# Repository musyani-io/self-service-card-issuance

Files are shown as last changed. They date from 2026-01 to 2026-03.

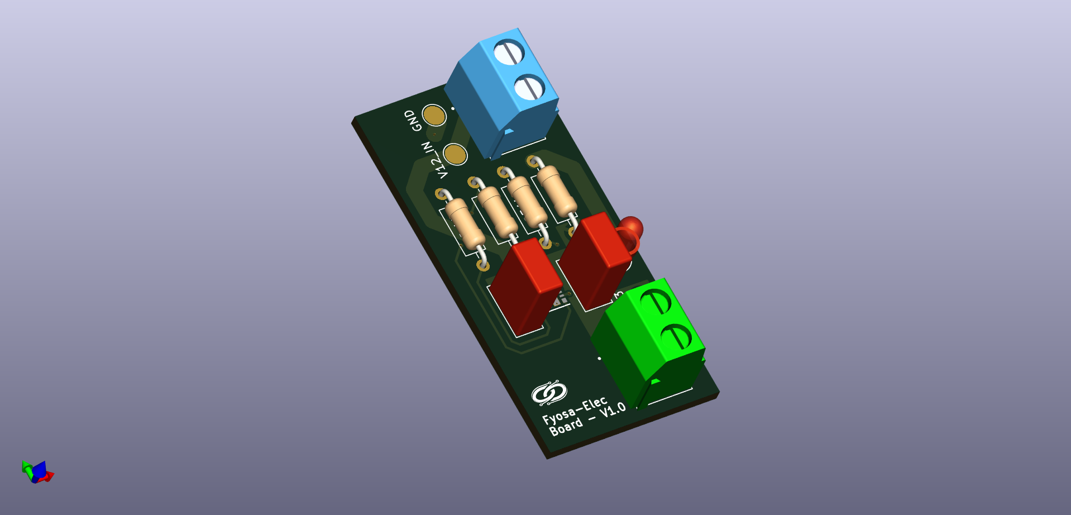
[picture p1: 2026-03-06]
hardware/3d/buck_3V3.png

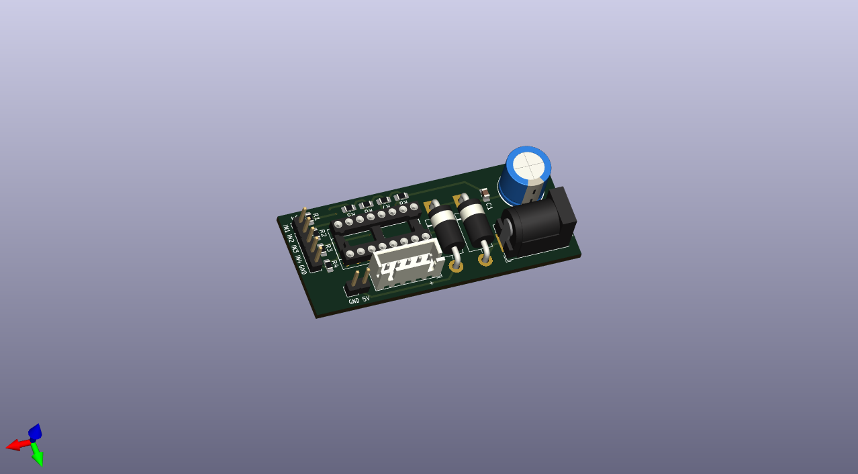
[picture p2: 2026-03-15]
hardware/3d/motor_driver.png

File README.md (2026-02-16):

# Self-Service Card Issuance System

Automated, secure, 24/7 student ID card distribution kiosk with a dual-controller architecture and full auditability.

## Overview

This system dispenses pre-printed student ID cards after identity verification. It is designed for unattended operation with deterministic control, mechanical safety, and a complete audit trail.

## System Architecture

Two controllers split responsibilities:

- **Raspberry Pi 5 (High-Level Control)**
  - User interface and session management
  - OTP-based authentication and policy enforcement
  - Computer vision pipeline for OCR/verification
  - Database access and audit logging

- **STM32 (Low-Level Control)**
  - Motor/actuator control and transport timing
  - Sensor acquisition (optical, limit switches, etc.)
  - Jam detection and recovery state machine
  - Hardware safety interlocks

Communication occurs over a 3.3V SPI link with a message protocol and acknowledgements to ensure safe, deterministic execution.

## Key Features

- **OTP Authentication**: SMS-based verification with configurable timeouts and retries
- **Computer Vision**: OCR-driven ID extraction with preprocessing and failure handling
- **Audit Trail**: Immutable transaction logs with timestamps and device context
- **Safety Enforcement**: Jam detection, limit checks, and fault isolation
- **Offline Tolerance**: Local caching for continued operation during network issues
- **Mock Hardware**: Back-end testing without physical hardware

## Repository Structure

- [DESCRIPTION.md](DESCRIPTION.md): Short project description and scope
- [backend/](backend/): Raspberry Pi application (auth, dispense flow, logging, DB access, communications)
- [computer_vision/](computer_vision/): CV pipeline for detection, OCR, and verification
- [hardware/](hardware/): Schematics, PCB layouts, BOMs, and EasyEDA project files
- [docs/](docs/): Research, system guidelines, and internal documentation
- [usage/](usage/): Minimal usage examples and entry points

## Data Flow (High Level)

1. User initiates session on the kiosk UI.
2. OTP is issued and verified.
3. The CV pipeline validates the card identity.
4. The Pi sends a dispense command to STM32.
5. STM32 executes the transport state machine and reports status.
6. Results and telemetry are logged.

## Hardware Integration

Hardware artifacts are organized under [hardware/](hardware/) and include:

- Schematics and PCB layouts
- BOMs and component datasheets
- EasyEDA project files

## Development Notes

- The Pi side is responsible for policies, logging, and vision.
- The STM32 side is responsible for deterministic actuation and safety.
- All dispense actions must be logged with outcome codes.

## License

See [LICENSE](LICENSE).

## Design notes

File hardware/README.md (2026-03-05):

# Hardware Design and Integration

This directory contains the electrical design, PCB layout, and mechanical specifications for the self-service card issuance kiosk controller board, designed using KiCAD.

## Design Overview

The hardware implements a dual-controller architecture:

- **Raspberry Pi 5**: High-level application control, UI, vision processing, and system logging
- **STM32 Microcontroller**: Real-time actuator control, sensor acquisition, and safety interlocks
- **SPI Communication**: 3.3V differential signaling for deterministic inter-controller messaging

## Design Files

KiCAD project files are located in [kicad/](kicad/) with four independent circuit modules:

- **buck_3V3.kicad_pro**: 12V → 3.3V buck regulator for logic and STM32 supply
- **buck_5V1.kicad_pro**: 12V → 5V synchronous buck regulator (10 A) for Raspberry Pi and peripherals
- **motor_driver.kicad_pro**: High-side MOSFET drivers and PWM control for DC motor actuation
- **reverse_polarity.kicad_pro**: Input reverse-polarity protection circuit using P-channel MOSFET

Each project includes schematic (.kicad_sch), PCB layout (.kicad_pcb), and project configuration files.

## Schematic Exports

Generated schematics are exported as PDFs in the [schematics/](schematics/) directory for documentation and reference.

## PCB Layout

PCB layout files and manufacturing exports are available in [pcb/](pcb/):

- Multi-layer stackup optimized for power distribution and thermal management
- Dedicated copper area under buck regulator SW nodes for heat spreading
- Ground plane separation (PGND/AGND) with single-point Kelvin connection

## Simulations

Circuit simulations and verification are performed in [simulations/](simulations/) using Proteus (.pdsprj files) for behavioral validation of power stages and driver circuits.

## 3D Models and Renders

3D visualizations are provided in [3d/](3d/):

- Component placement and thermal analysis renderings
- PCB assembly reference

## Bill of Materials

Component lists and sourcing information:

- [bom/motor_driver.csv](bom/motor_driver.csv): Motor driver stage components

## Component Datasheets

Reference datasheets for key active components are provided in [datasheets/](datasheets/):

- Buck regulator specifications and timing parameters
- Motor driver absolute maximum ratings and thermal considerations
- Reverse-polarity MOSFET characteristics

## Design Constraints and Specifications

- **Input voltage**: 12 V nominal (fused at 10 A)
- **Output rails**: 5 V @ 8 A (Pi/display), 3.3 V @ 3 A (logic/STM32)
- **Operating mode**: 12V → 5V buck in 1 MHz forced CCM for Raspberry Pi loads
- **Safety**: Dual fusing, reverse-polarity protection, limit switch monitoring on STM32

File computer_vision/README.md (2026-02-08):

# Computer Vision Module

## Overview

Image preprocessing and OCR detection module for the Automated Self-Service Student ID Card Issuance System. Handles image capture, preprocessing pipeline (grayscale conversion, resizing, ROI extraction), and OCR-based ID extraction for card identification and verification.

---

## Quick Start

### Installation

```bash
pip install -r requirements.txt
```

Ensure `opencv-python`, `pytesseract`, and `pillow` are installed in your environment.

---

## Module Structure

```bash
computer_vision/
├── core/              # Core CV functions (image_utils, ocr tools)
├── pipeline/          # Processing pipeline orchestration
├── config/            # Configuration files (camera, processing params)
├── tests/             # Manual and automated tests
├── data/              # Sample images, debug outputs, calibration data
├── docs/              # API reference, setup guides
└── utils/             # Logging, file I/O helpers
```

---

## Implementation Status

**Overall Progress: 14%** (6 phases)

**Phase 1: Environment Setup** 🚧 68%

- ✅ Software installation complete
- ✅ Development environment configured
- ⏳ Camera hardware acquisition pending
- ✅ Test data partially prepared

**Phase 2: Image Capture** ⏳ 0%

- ⏳ Camera configuration
- ⏳ Camera interface implementation
- ⏳ Testing suite

**Phase 3: Image Preprocessing** 🚧 16%

- ✅ Basic preprocessing functions (grayscale, resize, ROI crop)
- ⏳ Advanced preprocessing (blur, thresholding, morphology)
- ⏳ Processing pipeline
- ⏳ Testing suite

**Phase 4: OCR Detection** ⏳ 0%

- ⏳ OCR detection
- ⏳ OCR parsing/validation
- ⏳ Edge case handling
- ⏳ Testing suite

**Phase 5: Error Handling** ⏳ 0%

- ⏳ Custom exceptions
- ⏳ Exception integration
- ⏳ Retry logic

**Phase 6: Integration & Testing** ⏳ 0%

- ⏳ Public API
- ⏳ Database integration
- ⏳ End-to-end testing
- ⏳ Performance benchmarking

---

## Data Organization

### Input Images

Place sample ID card images in:

```bash
data/test_cards/
```

### Debug Outputs

Processed images saved to:

```bash
data/debug_outputs/
```

Includes intermediate preprocessing results for visual inspection.

---

## Dependencies

See [requirements.txt](requirements.txt) for full list.

---

## Notes & Limitations

- **No camera integration yet**: Works with static images only
- **Fixed orientation**: Assumes cards are consistently oriented
- **ROI hardcoded**: Bottom-half crop; configurable in future iterations
- **Testing environment**: Local development with mock data; not production-ready

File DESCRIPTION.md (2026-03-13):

# Automated Self-Service Student ID Card Issuance System

## Overview

This project implements a prototype **Automated Self-Service Student ID Card Issuance System** designed to securely distribute **pre-printed student ID cards** in a university environment. The system eliminates long queues, limited working hours, and manual sorting by enabling **on-demand, 24/7 card retrieval** through a secure, auditable, and electromechanically controlled kiosk.

The system focuses strictly on **card distribution**, not card printing or identity creation.

---

## Problem Statement

In many universities, including the University of Dar es Salaam, student ID cards are issued through a largely manual process:

- Cards are pre-printed and later distributed at college offices
- Students wait days to weeks before collection
- Distribution is constrained to working hours
- Staff must manually sort and handle large volumes of cards
- The process is prone to inefficiency, congestion, and human error

The bottleneck is **secure distribution**, not printing.

---

## Project Objective

### Main Objective

To design and implement an **automated, secure, and reliable self-service system** for issuing pre-printed student ID cards with full transaction logging and minimal human intervention.

### Specific Objectives

- Implement a deterministic actuator control system capable of selecting and dispensing a single card
- Implement secure student authentication using SMS-based One-Time Passwords (OTP)
- Implement computer vision for card identification and verification
- Maintain a complete audit trail of all transactions
- Enforce security policies for invalid attempts and physical tampering
- Evaluate system performance using measurable operational metrics

---

## System Scope and Limitations

### Included

- Secure dispensing of **pre-printed** ID cards
- Mechanical card transport, stopping, and storage
- OTP-based authentication
- Computer vision verification
- Local (mock) database for testing
- Audit logging and fault reporting

### Excluded

- On-device PVC card printing
- Payment or billing systems
- Mobile applications
- Direct access to live university databases (unless authorized)

---

## System Architecture

The system uses a **dual-controller architecture** to separate high-level decision logic from real-time mechanical control.

### High-Level Controller (Raspberry Pi 5)

Responsibilities:

- User interface (display, keypad, scanner input)
- SMS OTP generation and verification
- Database access and transaction logging
- Computer vision processing
- Security policy enforcement
- Issuing structured commands to the real-time controller

This controller handles **logic, authentication, and traceability**.

### Low-Level Controller (STM32)

Responsibilities:

- Real-time motor and actuator control
- Sensor acquisition (optical sensors, limit switches, jam detection)
- Deterministic execution of card transport and dispensing
- Mechanical safety enforcement
- Status and fault reporting to the high-level controller

This controller handles **physical determinism and safety**.

### Communication

- Protocol: SPI
- Logic level: 3.3 V
- Direction: Command–status exchange between Raspberry Pi and STM32

---

## Card Handling and Transport Concept

- Cards are **pre-printed** and manually loaded by authorized staff
- Each card contains a **printed student ID** used as a unique identifier (OCR)
- Cards are stored in indexed compartments
- A roller-based transport mechanism:
  - Accepts cards from the input slot
  - Moves cards to a camera inspection point
  - Stops cards at a repeatable reference position
  - Routes cards to storage or rejects them back to the user

All motion is **mechanically constrained** to ensure alignment and repeatability.

---

## Functional Workflow

### 1. Preload and Mapping Phase (Staff Operation)

- Staff loads pre-printed cards into the machine
- Each card is scanned using a camera
- Card student ID (OCR) is mapped to a storage index and student record
- Mapping is stored in the database

### 2. Notification Phase

- Once cards are available, the system sends an SMS notification
- Each message includes an OTP valid for a single retrieval attempt

### 3. Retrieval Phase (Student Operation)

1. Student inserts or scans their expired ID card
2. Student details are displayed on the screen
3. Student enters the OTP received via SMS
4. System verifies identity and OTP
5. High-level controller authorizes dispensing
6. Low-level controller retrieves and ejects the correct card
7. Transaction is logged for auditing

### 4. Rejection and Error Handling

- If verification or vision checks fail:
  - Card can be safely rejected back to the user
- If mechanical or security faults occur:
  - System halts and notifies the administrator

---

## Security Model

### Logical Security

- SMS-based OTP authentication
- Limited retry attempts
- Temporary lockout after repeated failures
- Database-backed audit logging

### Physical Security

- Tamper detection sensors
- Jam and stall detection
- Motor torque limiting
- Manual administrator reset for recovery

The system prioritizes **human safety over mechanical force**.

---

## Performance Evaluation Metrics

The prototype is evaluated using:

- Authentication success rate
- Average card retrieval time
- Dispense accuracy (correct card delivered)
- Fault detection and recovery effectiveness
- System uptime and reliability

---

## Key Engineering Contributions

- Application of vending-machine principles to sensitive identity distribution
- Correct separation of real-time and non-real-time system responsibilities
- Secure, auditable automation for institutional ID management
- Mechanically enforced precision to reduce software complexity

---

## Intended Use

This prototype is intended for:

- Academic evaluation
- Demonstration of embedded systems integration
- Exploration of secure automated kiosks in institutional environments

It is **not** intended for direct deployment without further industrial hardening.

---

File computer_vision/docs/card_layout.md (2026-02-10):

# Student ID Card Layout Documentation

**Purpose:** Document the physical and logical layout of your university's student ID cards to guide OCR implementation.

**Card Type/Version:** University of Dar es Salaam - from 2022 Editions  
**Measured By:** Samuel Dan Musyani

---

## 1. Physical Card Specifications

### Card Dimensions

- **Width:** 88 mm
- **Height:** 55 mm
- **Standard:** CR80 (Almost this standard)
- **Thickness:** 1 mm

### Card Material

- Material: PVC
- Surface finish: Glossy
- Color: Whitish background

### Printing Quality

- Print quality: Fair
- Text clarity: Low contrast
- Any visible wear on sample cards? Yes

---

## 2. Student ID Field Specification

This is the **PRIMARY** field your OCR system must extract.

### Location on Card

From **top-left corner** of the card:

- **Distance from left edge:** 1.5 mm
- **Distance from top edge:** 29 mm
- **Width of ID field:** 23 mm
- **Height of ID field:** 3.5 mm

### ID Format

- **Exact format pattern:** 2020-04-12345
- **Regex pattern:** `r'\d{4}-\d{2}-\d{5}'`
- **Total characters:** 13 (including separators)
- **Numeric only?** Yes (with hyphens)
- **Special characters:** Hyphens

### Sample Valid IDs

```bash
- 2022-04-07227
- 2022-04-11472
- 2022-04-09050
```

### ID Field Properties

- **Font name:** Calibri
- **Font size:** 9 pt
- **Font style:** Bold
- **Text color:** Blue
- **Background color/pattern:** Whitish
- **Text orientation:** Horizontal
- **Fixed-width font?** Yes

---

## 3. Additional Text Fields (Secondary)

### Field 1: Student Name

- **Location:** 1.5 mm from left, 21 mm from top, 57mm width, 4 mm height
- **Format:** Structured (`last_name, first_name middle_name`)
- **Font:** Calibri, Size: 9 pt, Color: Blue, Type: Bold
- **Purpose in system:** Display

### Field 2: Program/Major

- **Location:** 1.5 mm from left, 37 mm from top, 57 mm width, 4 mm height
- **Format:** B.Sc. in `Course name` (Electronics Engineering, Telecommunication Engineering)
- **Font:** Calibri, Size: 9 pt, Color: Red, Type: Blue
- **Purpose in system:** Display

### Field 3: Card Expiry Date

- **Location:** 18 mm from left, 40 mm from top, 21 mm width, 4 mm height
- **Format:** "DD/MM/YYYY"
- **Font:** Calibri, Size: 9 pt, Color: Red, Type: Bold
- **Purpose in system:** Validation

---

## 4. ROI (Region of Interest) Coordinates

These will be used to extract specific text regions during OCR.

**Calculation method:** Coordinates as **percentage** of card width/height (0.0 to 1.0).

### Anchor-Based ROI (Final Offsets)

Anchor label: **NAME** (top-left of the anchor text box). Offsets are fractions of card width/height from the anchor top-left.

```python
ANCHOR_ROI_OFFSETS = {
    'name': {
        'dx': -0.008,
        'dy': 0.064,
        'w': 0.648,
        'h': 0.073,
    },
    'student_id': {
        'dx': -0.010,
        'dy': 0.203,
        'w': 0.261,
        'h': 0.086,
    },
    'program': {
        'dx': -0.013,
        'dy': 0.322,
        'w': 0.648,
        'h': 0.072,
    },
    'expiry_date': {
        'dx': 0.166,
        'dy': 0.394,
        'w': 0.238,
        'h': 0.073,
    },
}
```

---

## 5. Challenges and Special Considerations

### Text Recognition Challenges

- [x] Low contrast text
- [x] Reflective/glossy surface causes glare
- [x] Background pattern/watermark interferes with OCR
- [ ] Font is unusual or ornamental
- [ ] Text is very small
- [x] Colored text (not black)

### Positioning Challenges

- [ ] ID field location varies between card batches
- [ ] Card might be slightly rotated when inserted
- [x] Multiple text regions close together

### Environmental Challenges

- [ ] Card might have stickers/tape on it
- [x] Card edges are worn
- [ ] Card is laminated/sealed

---

## 7. Reference Images

### High-Quality Reference Card

- Save a clean, well-lit photo: `data/test_cards/reference.jpg`
- Annotate with anchor label if possible: `data/test_results/reference_annotated.jpg`
- Include measurements marked on image

### Multiple Sample Cards

Create a directory with diverse examples:

```bash
data/test_cards/
  ├── reference_card_front.jpg          (high quality, well-lit)
  ├── sample_card_01.jpg                 (typical condition)
  ├── sample_card_02.jpg
  ├── sample_card_challenging_01.jpg    (poor lighting)
  └── sample_card_challenging_02.jpg    (damaged/worn)
```

---

## 8. Configuration Template

Once you've documented above, use this template for `config/ocr_config.py`:

```python
# Card Layout Configuration
# Based on physical measurements from card_layout.md
# University of Dar es Salaam - 2022 Edition Cards

CARD_PHYSICAL = {
    'width_mm': 88,
    'height_mm': 55,
    'standard': 'CR80',  # Close to CR80 standard (85.60×53.98mm)
}

# Standard output size for perspective-corrected cards
# Maintains aspect ratio: 88/55 = 1.6
CARD_OUTPUT_SIZE = (880, 550)  # Width × Height in pixels (10px per mm)

ANCHOR_OCR = {
    'anchor_texts': ['NAME'],  # Update to the exact printed label on your card
    'min_confidence': 50,
    'psm': 6,
    'oem': 3,
    'char_whitelist': 'ABCDEFGHIJKLMNOPQRSTUVWXYZ: ',
}

# Offsets relative to anchor top-left (fractions of card width/height)
ANCHOR_ROI_OFFSETS = {
    'name': {
        'dx': 0.000,
        'dy': 0.000,
        'w': 0.648,
        'h': 0.073,
    },
    'student_id': {
        'dx': 0.000,
        'dy': 0.145,
        'w': 0.261,
        'h': 0.064,
    },
    'program': {
        'dx': 0.000,
        'dy': 0.291,
        'w': 0.648,
        'h': 0.072,
    },
    'expiry_date': {
        'dx': 0.188,
        'dy': 0.345,
        'w': 0.238,
        'h': 0.073,
    },
}

# Student ID Validation
STUDENT_ID_PATTERN = r'\d{4}-\d{2}-\d{5}'  # Format: 2022-04-07227
VALID_YEAR_RANGE = (2015, 2030)
ID_TOTAL_LENGTH = 13  # Including hyphens

# OCR Settings
TESSERACT_CONFIG = {
    'psm': 6,  # Assume uniform block of text
    'oem': 3,  # Default OCR Engine Mode
    'char_whitelist': '0123456789-',  # Only digits and hyphens for ID
}

# Font Properties (for reference)
FONT_PROPERTIES = {
    'name': 'Calibri',
    'size_pt': 9,
    'style': 'Bold',
    'color': 'Blue',  # Text color (may need color-specific preprocessing)
}

# Known Challenges
CHALLENGES = [
    'Low contrast text (blue on white)',
    'Glossy surface causing glare',
    'Background watermark interference',
    'Colored text (not black)',
    'Card edge wear',
    'Multiple text regions close together',
]
```

---

## 9. Measurement Checklist

Before proceeding to Phase 2, verify you have:

- [x] Physical card dimensions documented
- [x] Student ID format with regex pattern defined
- [x] Student ID location measured (from top-left corner)
- [x] Student ID font properties recorded
- [x] ROI percentages calculated
- [x] At least one reference card image saved
- [ ] At least 5 sample cards photographed at various angles
- [x] All challenges/variations listed
- [ ] Card layout diagram or annotated image created

---

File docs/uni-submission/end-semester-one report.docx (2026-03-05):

UNIVERSITY OF DAR ES SALAAM

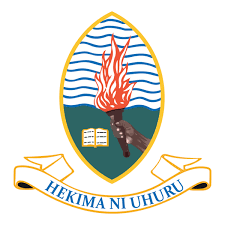
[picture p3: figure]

COLLEGE OF INFORMATION AND COMMUNICATION TECHNOLOGY

DEPARTMENT OF ELECTRONICS AND TELECOMMUNICATIONS ENGINEERING

FINAL YEAR REPORT-MID SEMESTER ONE

PROJECT TITLE: DESIGN AND IMPLEMENTATION OF AN AUTOMATIC ID CARD ISSUANCE SYSTEM

Student’s Name: Samuel Dan Musyani

Registration Number: 2022-04-09050

Supervisor’s Name: Dr. Hashimu Iddi

Supervisor’s Signature:

# ABSTRACT

The issuance of student identification cards in many higher learning institutions is often characterized by long processing times as a result of manual verification within a narrow working window. This project proposes the design and implementation of an automated self-service student ID card issuance system aimed at improving efficiency, security and all-time reliability of issuance process. The system is an embedded system with peripheral devices for user authentication, data collection, card issuance, back-end communication together with database access. The proposed project will be evaluated based on authentication success rate, dispense rate, issuance accuracy, and system’s reliability.

The outcome of this project is expected to be a functional prototype demonstrating an automated secure student ID card issuance system suitable for University environments.

# TABLE OF CONTENTS

# LIST OF TABLES

# LIST OF FIGURES

# LIST OF ABBREVIATIONS

ABBREVIATIONS | LONG FORM
2FA | 2-Factor Authentication
API | Application Program Interface
CAD | Computer Aided Design
CLK | Clock
CS | Chip Select
DB | Database
GB | Gigabyte
ID | Identification
IoT | Internet of Things
MISO | Master In Slave Out
MOSI | Master Out Slave In
OCR | Optical Character Recognition
OS | Operating System
OTP | One Time Password
PVC | Poly-Vinyl Chloride
PWM | Pulse-Width Modulation
RAM | Random Access Memory
SMS | Short Message Service
SPI | Serial Peripheral Interface
Wi-Fi | Wireless Fidelity

# CHAPTER ONE: INTRODUCTION

## 1.1 BACKGROUND

Universities commonly issue student ID cards that serve as proof of registration and campus identification for various services to students. At the University of Dar es Salaam, the card collection process, which occurs immediately after students have completed registration, involves queuing at the responsible office for collection. However, for a high volume of students, this results in long waiting times, narrow service windows (only operating during working hours), and staff exhaustion.

Therefore, the project aims to develop a prototype of an Automated ID Card Issuance System that sorts and gives out pre-printed ID cards to students on demand at all times. The system integrates a microcontroller that controls actuators in real-time, a single-board computer that performs computer vision (for ID identification), student’s identity authentication, logging of various activities, and back-end integration. The intended solution aims to reduce distribution time while ensuring secure ID card distribution as it is.

## 1.2 PROBLEM STATEMENT

The current student ID card issuance process at University of Dar es Salaam involves a waiting period of approximately one week after registration due to delayed card availability in the individual’s college. After release, the card collection also requires students to queue and sort a bunch of ID cards. So, for a high volume of students, the staff responsible suffers significant work strain. On top of that, fixed hours also hinder the sorting capacity of students' issuance per time. As a result, card issuance for registered students takes up to several days, which may bring inconvenience to students.

## 1.3 MAIN OBJECTIVE

Design and implementation of an Automated ID Card Issuance System for pre-printed student ID cards with secure authentication and audit logging while serving students at all times.

## 1.4 SPECIFIC OBJECTIVE

1. To implement a reliable control system for actuators using a microcontroller capable of selecting and dispensing a single card from a pile of cards in a stored compartment.
2. To implement a computer board application that gives out authentication OTPs, verifies the student’s set pin, receives the user registration data, verifies it against a database, and communicates the command to the microcontroller.
3. To implement robust logging of each transaction details in database for auditing and debugging.
4. To implement security policy that uses SMS-delivered OTPs as authentication mechanism, and also enforce measures to deal with invalid attempts and communication to system admin.
5. To evaluate system performance using metrics such as average card retrieval time, authentication success, error handling and dispense rate.
6. To produce a formal report involving design of the prototype at various milestones.

## 1.5 SIGNIFICANCE OF STUDY

- Operational efficiency: the proposed system reduces long queues and waiting times by allowing students to retrieve ID cards on demand without any staff intervention.
- Reduced administrative burden: the system performs automation which replaces the repetitive tasks done by a university staff allowing them to focus on higher level tasks.
- Scalability, accessibility and replicability: Although the proposed system is implemented as a prototype for UDSM, the system can be adopted by other institutions such as banks for card applications. Also, access to students retrieving their ID cards beyond standard normal working hours.
- Academic contribution: the project demonstrates practical application of embedded systems, back-end software and other mechanical design theory and automation studied as theory in various academic year(s).

## 1.6 SCOPE AND LIMITATIONS

This project focuses on the design and implementation of an Automated ID Card Issuance System which integrates the software part (back-end, user interaction and computer vision verification) and hardware part with microcontroller and actuators for card sorting and dispensing the said card. Therefore, the prototype does not implement on-device printing of the PVC cards, mobile application or payment gateway.

The system intends to use a mock database for testing unless institutional access is granted.

# CHAPTER TWO: LITERATURE REVIEW

In this chapter, various existing systems, projects and technologies related to the proposed project are reviewed. The purpose of the review is to understand different approaches, scope, limitations and gaps and hence, establish basis of the proposed project. Therefore, the following points gathered below feature ideas with similar concepts as the proposed project.

## 2.1 RELATED PROJECTS

- Automatic and Smart Vending systems: these are some self-service systems that provide mostly goods (foods) to users without much human intervention, mostly observed in supermarkets for snacks and beverages. These systems have two categories: non-IoT machines, which operate by giving physical cash to the machine, and IoT machines, which work with cashless payments and track the availability of stock, locations to satisfy customer preferences by using microcontrollers (Ratnasri & Sharmilan, 2021). Also, some vending systems apply image processing with deep learning to detect and categorize various target objects of interest in the image. These kinds of vending machines also implement a weight data acquisition part to increase the accuracy of target object detection (Xia, K., Fan, H., Huang, J., Wang, H., Ren, J., Jian, Q., & Wei, D).
- System architectures and control strategies: in most of the dispensing applications, generally a microcontroller is used with a communication module, mostly Wi-Fi, with a logic to directly manage actuator control, sensor inputs, safety interlocks, and communicate with the server or a computer for other complex tasks (Prasad, Kumar, Shriram, Prof. Dr. Mane, 2024).
- Authentication and security: this is one of the most critical part of the system that deals with sensitive items. In automated environments, combining multiple verification layers (e.g OTP, biometrics, card scanning) improves security. In ATM systems, work on authentication explores multi-factor approaches, integrating OTPs with biometric factors to reduce unauthorized access risk (Kibaya, Lubobya, 2024).

## 2.2 RESEARCH GAP

From the related projects, the proposed system aims to cover the gap that despite an extensive research on vending and kiosk systems, limited number of projects addresses secure low-cost automated distribution of pre-printed identification cards particularly in University environments.

# CHAPTER THREE: SYSTEM DESIGN AND METHODOLOGY

This chapter reviews various procedures to design, build and evaluate the performance of the prototype. It covers system architecture, hardware and software selection together with some security measures.

## 3.1 SYSTEM ARCHITECTURE

High-level controller will be used to control the user interface, network connectivity, 2FA for OTP and student’s pin, database access, computer vision verification, transaction logging, and command issuing to the real-time controller. Then, a real-time controller will be used to directly control the motor (PWM), safety monitoring (limit switches), status reporting, and mechanical card sorting and ejection.

The pre-printed cards will be organized in indexed storage sections, which will be mapped to existing barcodes on the ID cards. Local (mock) database will be used to replicate the University DB scheme, and testing will emulate that unless permission is granted to access the database (API).

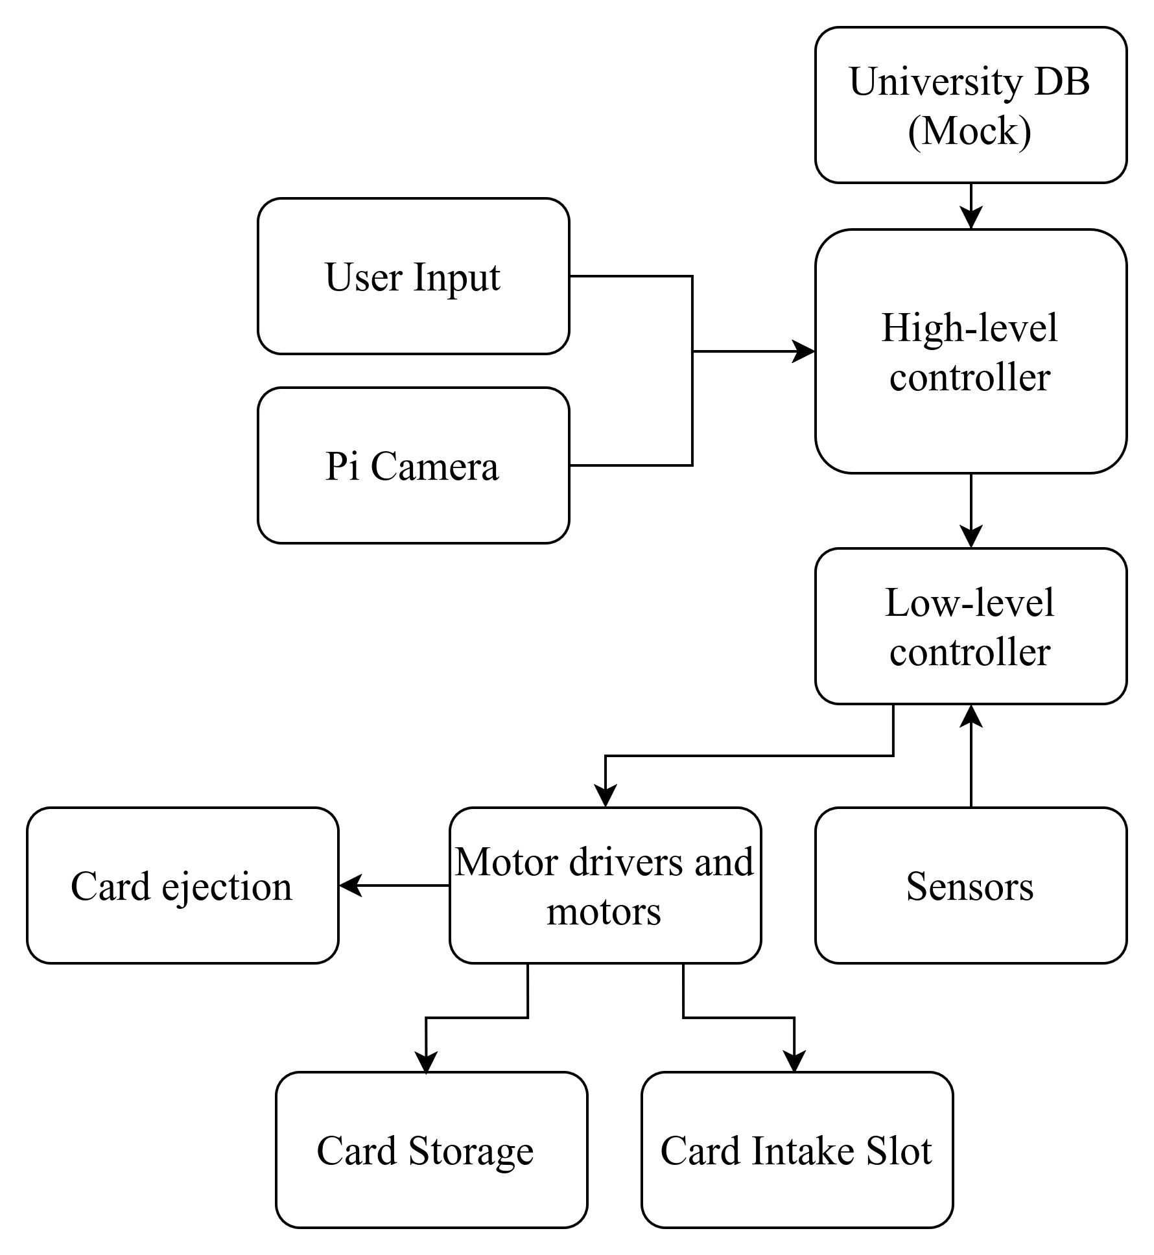
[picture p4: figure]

Figure 1: System’s block diagram

## 3.2 FUNCTIONAL WORKFLOW

- Preload phase: responsible staff inserts a bunch of pre-printed cards into the dispenser, then the machine runs a routine scan and maps each card into a slot index in the dispenser DB. The high-level controller records the mapping with the individual card.
- Notification phase: when the cards are available, right after the routine scan, the high-level controller initiates triggering of SMS to particular students. The SMS includes an OTP valid for one retrieval attempt. If it is the particular student’s first time use, and extra different and temporary pin is sent via SMS for 2FA.
- Retrieval phase: First, students scan their expired card, and their information is shown on the screen (registration number, name, and degree programme), then an OTP prompt follows, as received from the SMS. Thereafter, the high-level controller validates the OTP and prompts for the student’s pin for extra layer of authentication. If it is the student’s first time use, after the prompt, the system gives a form to register a new custom pin which will be permanent for each individual.

After that, high-level sends the dispense command to the low-level controller to start the card dispensing process. The low-level microcontroller executes the motion to retrieve the card and verifies the card and its presence, and performs ejection while updating and returning the status to the high-level controller. Lastly, the high-level controller logs the transaction to the database as the audit logs.

- Security measures: after 3 invalid attempts for the same registration number within the same session, the system flags that particular number as locked for amount of time, notifies the system admin and returns to the home screen. In addition to that, in case of any physical tampering, the system alerts the admin and shuts down until manual admin reset is performed.

Below are the functional workflows featuring both student-side and staff-side access of the system:

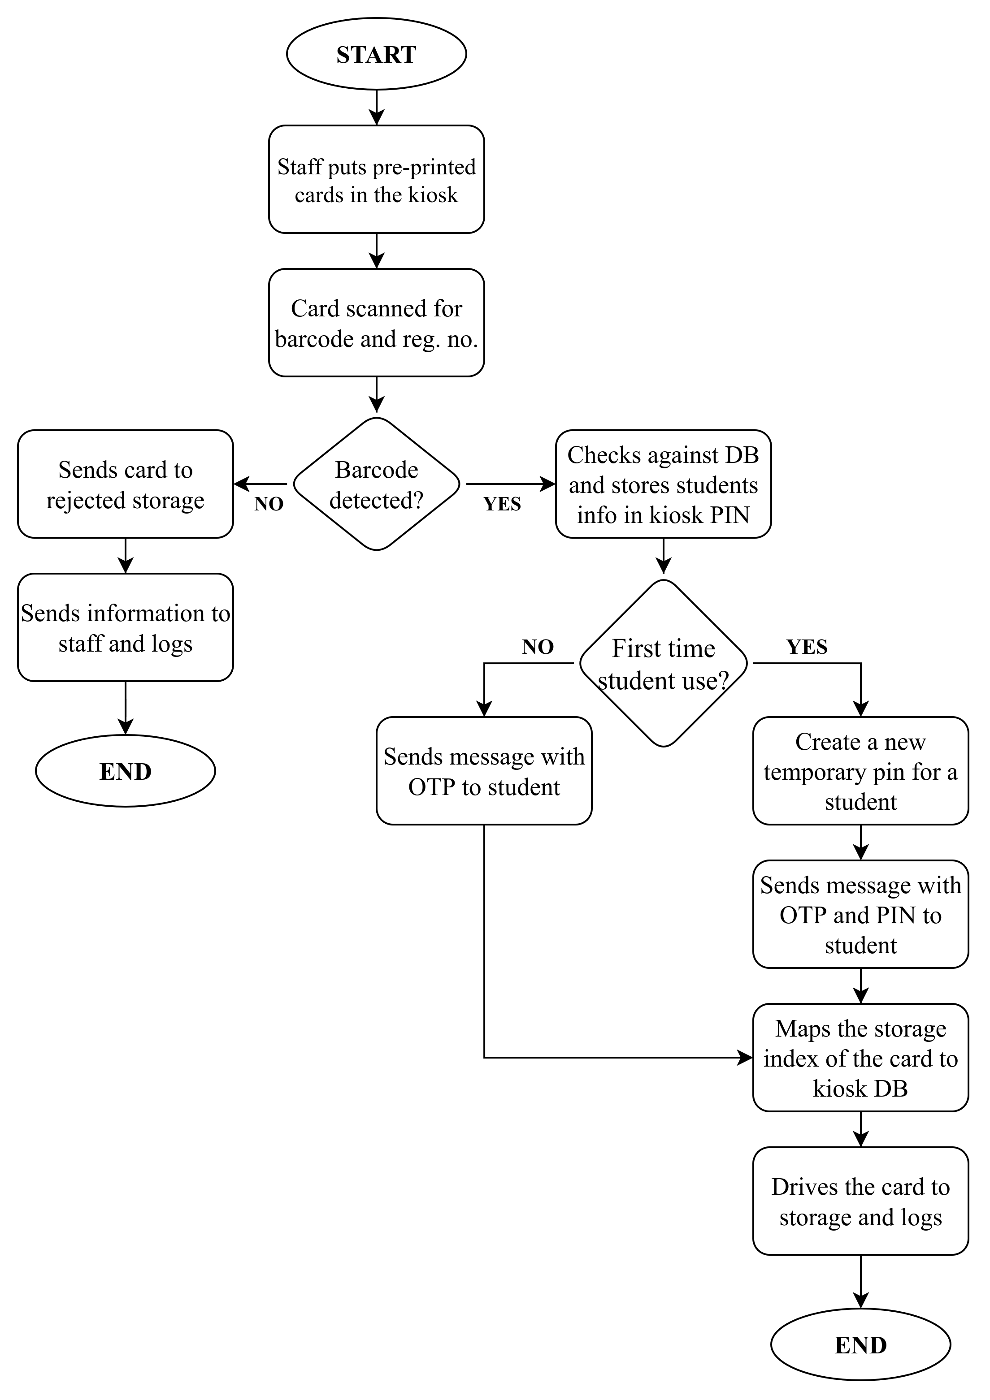
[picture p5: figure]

Figure 2: Staff-side functional workflow

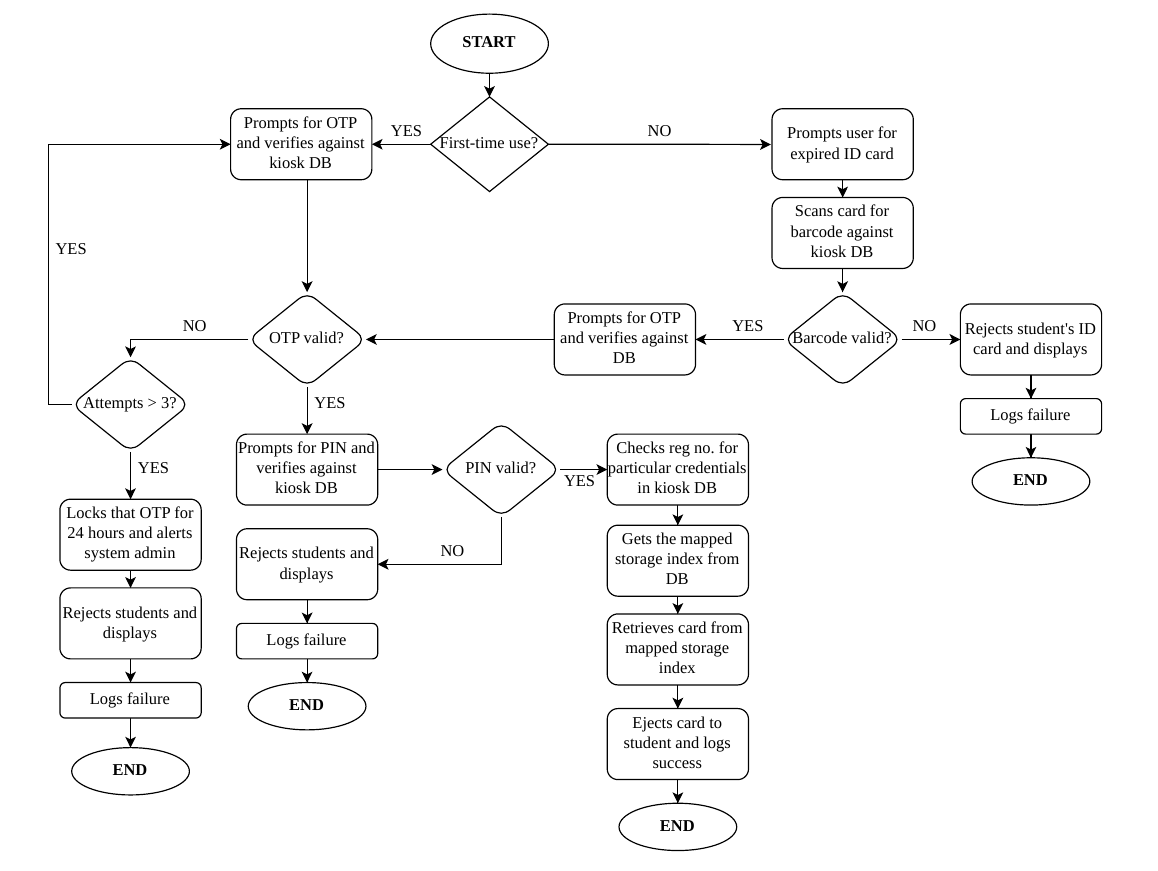
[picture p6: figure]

Figure 3: Student-side workflow

## 3.3 COMMUNICATION PROTOCOL

The communication protocol targeted between high-level controller and low-level controller is SPI, which has four wires (CLK, MOSI, MISO, CS) plus common ground, where Raspberry Pi is the master, with STM32 as its slave. All these communication signals operate at 3.3V.

This communication protocol was selected due to high speed synchronous communication, full-duplex capability, simple hardware implementation and very reliable short distance communication.

Within this protocol, the commands (light messages) will be the ones to initiate various activities by the high-level controller through low-level controller done by the actuators.

## 3.4 SYSTEM CIRCUIT DESIGN AND ITS ARCHITECTURE

### 3.4.1 COMPONENTS USED

The hardware and software tools selected for this project were chosen based on their performance requirements, need for scalability and compatibility with each other.

- Raspberry Pi 5 (4GB RAM): hosts back-end application, OTP generation, database access, logging, computer vision and communication with low-level controller.
- Low-level controller: directly drives actuators, reads sensors, timing and safety logic, detects mechanical faults and reports status to Raspberry Pi.
- Camera module: visual images for card to support computer vision tasks.
- Actuators: Move sorting mechanisms, control card selection and ejection.
- Motor drivers: amplify control signals to drive motors safely.
- Sensors: identify various conditions, detect jams and misalignments.
- Power Supply: provides regulated power to components of the system

The following are the software proposed to be used in this project:

- Raspberry Pi OS: supporting system of the high-level controller.
- Back-end Application: handles user input, authentication, interfaces with database, sends commands to low-level controller and manages error handling.
- Database: stores students data and logs.
- Computer Vision libraries: supports card insertion and ejection verification.
- Low-level controller Firmware: executes motor control routines, reads sensors, implements communication and monitors safety.

### 3.4.2 HARDWARE CIRCUIT ARCHITECTURE

The hardware part of the Automated ID Card Issuance System is designed to support controlled mechanical actuation, stable power distribution and reliable communication between controllers. The circuit design was developed using KiCAD. The architecture design is divided into various design modules which include power regulation sub-system, STM32 core circuit control circuit, motor driver and actuation circuit and communication circuit interface.

### 3.4.3 POWER REGULATION

The system uses two controllers using different voltage levels (5V-Raspberry Pi and 3.3V-STM32) each with its own maximum current capabilities. The design of the system has one source of power with 12V and 8A current capabilities. The power source is equipped with a reverse polarity protection circuit for protection as shown below:

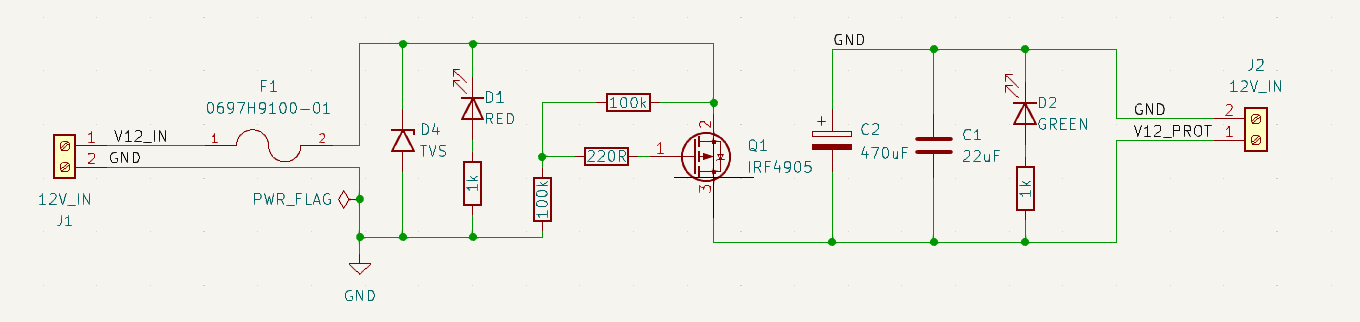
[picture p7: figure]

Figure 4: Reverse polarity circuit

The aim of this circuit is to prevent any damage which may be caused by exchange in polarity connections in the input. Thus, this configuration is expected to give zero output voltage when the input polarities are not in order.

In addition to that, 12V from the power source is stepped down by buck converters each to its desired parameters. For 5V voltage level, the design implemented the use of LMZ23610 buck converter with a current rating of 10A for thermal margin mainly. The schematic design as instructed from the data sheet is as shown below:

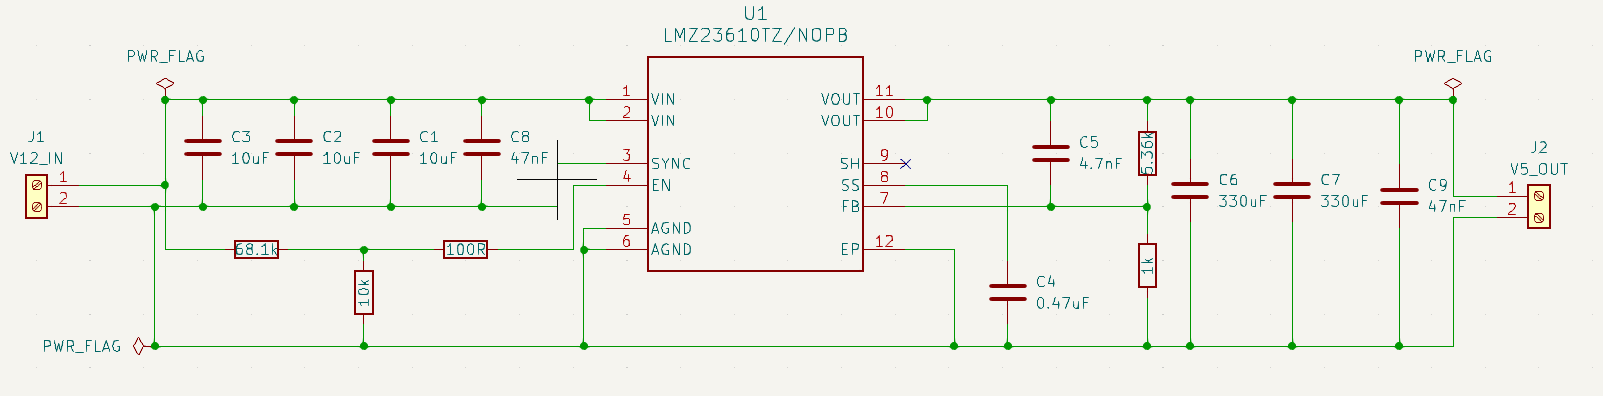
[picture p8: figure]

Figure 5: LMZ23610 schematic design for 5V output.

Moreover, for 3.3V voltage level, the design was implemented by using a PTSM82903 buck converter with current capability of 3A for thermal margin. This ensures the input voltage at 12V is stepped down to the desired level 3.3V with a stable output due to its load regulation capacity. The schematic design was as instructed from the data sheet to give out the desired results:

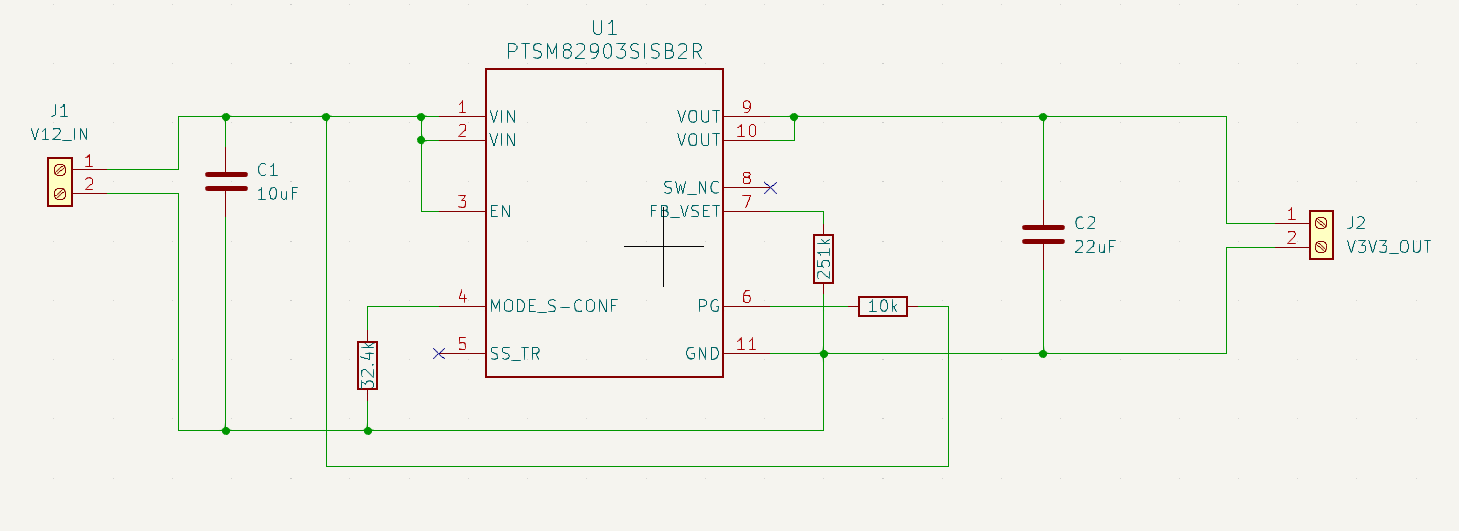
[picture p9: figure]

Figure 6: PTSM82903 schematic design for 3.3V output.

### 3.4.4 STM32 CORE CIRCUIT DESIGN

The STM32 controller defines a real-time control of the system’s actuation and deterministic behaviours. Therefore, the core design includes: proper power supply connections with decoupling capacitors to reduce power supply variations and configuration of boot pins.

STM32 programming interface application to be used will be STM32CubeMX, together with STMicroelectronics IDE together to program a low-level microcontroller used. At this stage, those applications uses a way of debugging that needs a hardware (chip or board) which is not yet implemented. On the next stage of this project, programming and implementation of the project will follow along.

### 3.4.5 MOTOR DRIVER AND ACTUATION CIRCUIT DESIGN

The actuation sub-system is designed to control DC stepper motors responsible for card transport and dispensing. The motor driver circuit is designed to interface with an MCU (STM32) through various control inputs and enable logic to drive the motors efficiently.

The motor driver power supply is the 5V power rail which is electrically separated from the logic. Below is the schematic diagram showing the connection configuration of the motor driver driving the stepper motor from logics of the micro-controller. This motor driver circuit is designed to also accept dual power sources, either from an adapter or a terminal block.

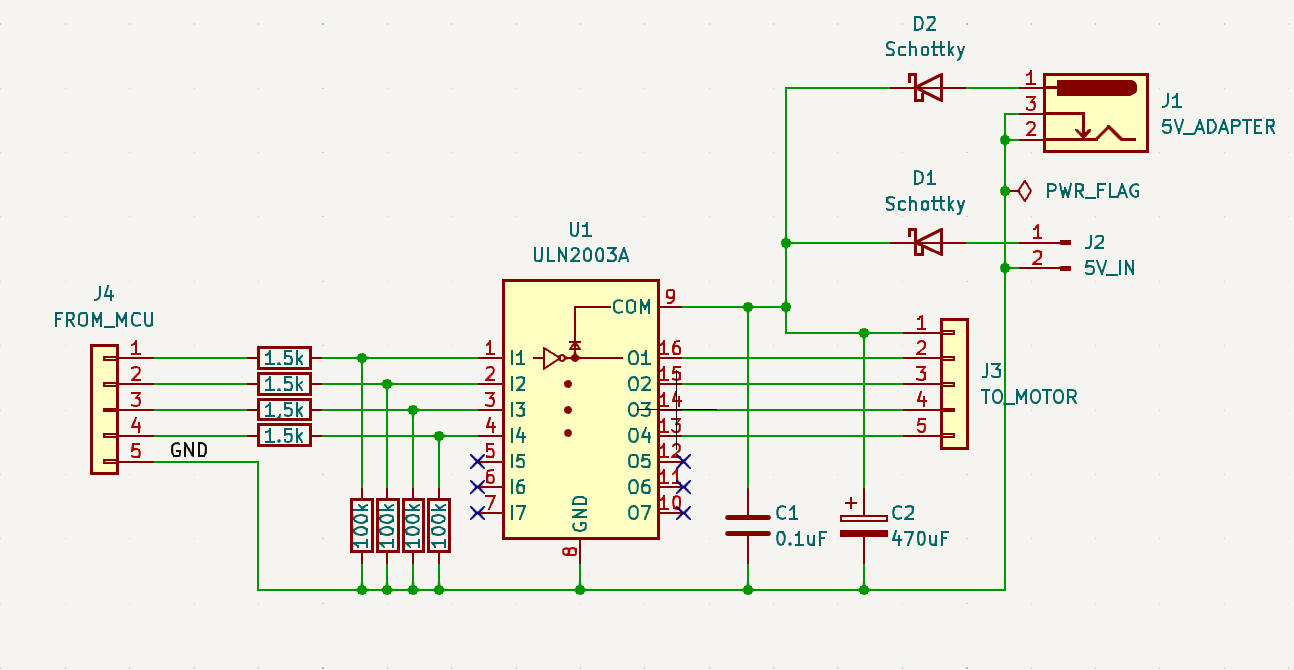
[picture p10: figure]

Figure 7: Motor driver connection schematic

## 3.5 COMPUTER VISION DESIGN INTEGRATION

The computer vision module’s aim is to detect and extract information from the inserted cards, either by the students or staffs. It performs OCR-based extraction of student’s registration number. The extracted data was chosen to be the registration number because it is unique for each student with no duplicate complications.

### 3.5.1 DESIGN DETAILS

The initial barcode-verification revealed some sensitivity to orientation variation and reflection hence OCR-based design was selected to reduce dependency on alignment of the card with lights and flexibility since text are relatively larger hence easier to identify than the barcodes.

### 3.5.2 PROCESSING PIPELINE

The proposed system design factored the PI camera capturing images of the cards, and the high-level controller processing them to extract the registration via OCR-based detection methods. Therefore, the processing pipeline consists of the following stages:

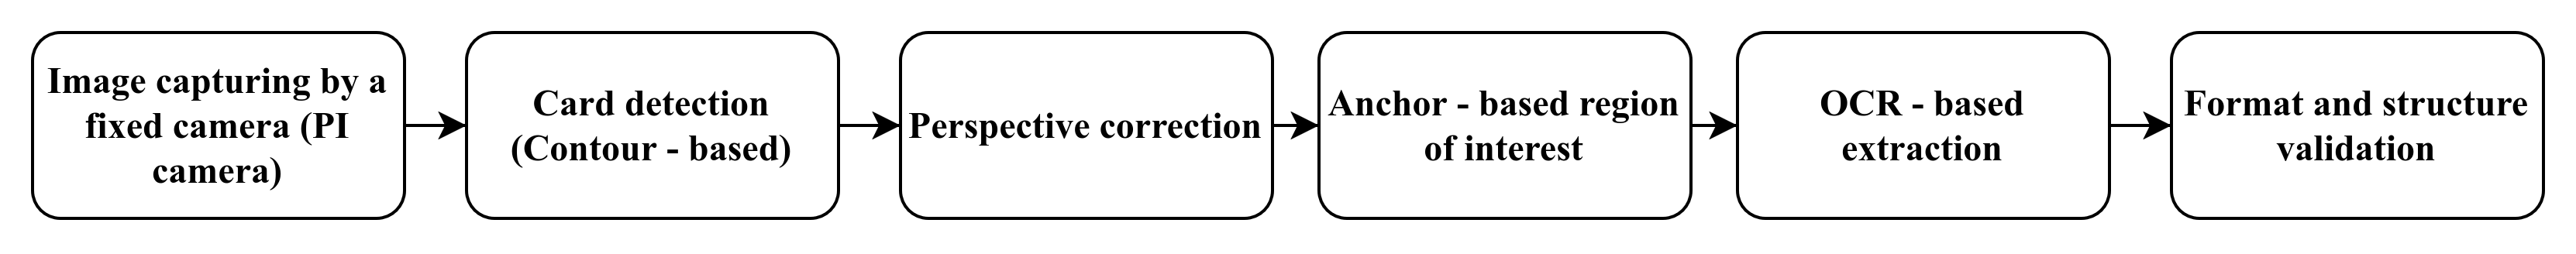
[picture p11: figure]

Figure 8: Processing pipeline workflow

From the functional workflow, card detection is designed using edge detection and contour extraction techniques which are filtered according to geometric constraints such as minimum area and aspect ration according the CR80 standard card size. Once a contour is detected, a perspective transformation is done to obtain a clear frontal view of the card to improve OCR detection stability.

To avoid relying solely on pixel coordinates, the design used incorporated anchor-based localization with a known reference on the card used “NAME”. After locating the reference, relative offsets (in pixels) are applied to extract the region where the registration number is expected to be from the anchor chosen.

The extracted region is processed used OCR, and configured to prioritize numeric text recognition first. Then, after extraction by OCR, the expected format of registration number “YYYY-NN-XXXXX” is validated. Only the text that fits the description of format is considered as success.

## 3.6 BACK-END AUTHENTICATION DESIGN

The back-end system is designed to manage identity validation, authentication control and system logging for audits. Therefore, it acts as a bridge between the computer vision results and the low-level controller activities. If the authentication goes wrong, low-level controller cannot perform any mechanical activity. The sub-system performs three important services:

- Student verification service
- OTP Authentication service
- Audit logging service.

After a successful extraction of the registration number from computer vision processes, the back-end verifies the number against the University database and fetches information about the particular student and stores the registration number to the local system’s database. Only valid and active records are passed to authentication.

The main authentication mechanism is based on a One-Time Password (OTP) model. Each OTP produced is designed according to standard security principles:

- Randomized OTP generation
- Secure storage using hashing
- Time-limited validity
- Restricted number of attempt.

The OTP delivered to the student using a SMS gateway. During retrieval, the student inputs the received OTP through the user interface designed. Back-end then compares the hashed input against the stored and logs the action in either case, failure or success. The logging design ensures accountability and traceability.

## 3.6 MECHANICAL DESIGN

As the system requires a staff to load a pile of cards into a machine, and it sorts out each card according to the information and stores it, here is the design of it. The card sorting and storage system, will be a combination of servo motor and a circular bin calculated with each slot to an assigned mapped number stored in the system’s database. If the card is needed, the bin is rotated by the servo motor up to the calculated position and a card is taken/ejected from the bin.

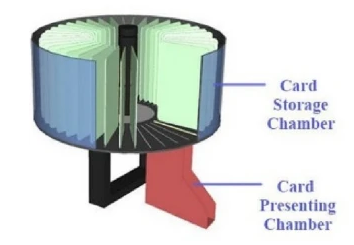
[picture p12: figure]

Figure 9: Circular storage chamber

## 3.7 PROJECT SCHEDULE

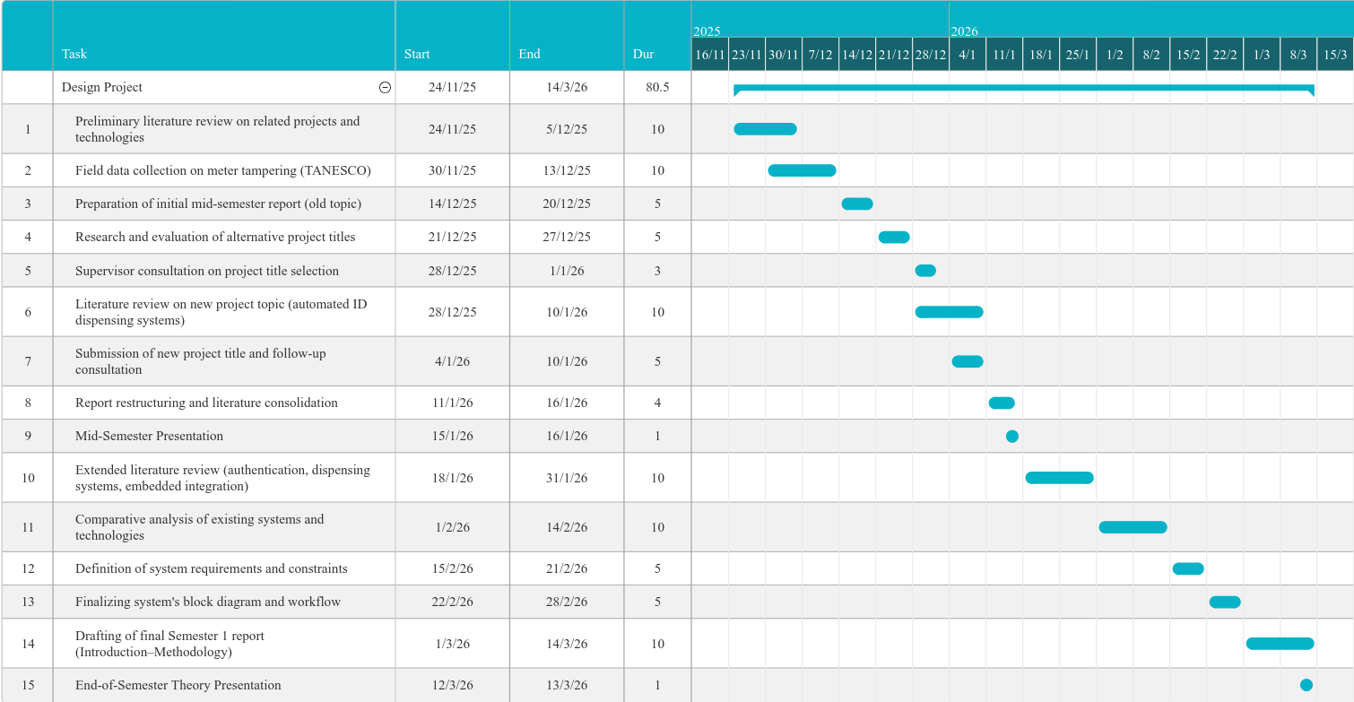
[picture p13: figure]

For first semester, the following Gantt chart shows various activities planned for proposed system:

Figure 10: Semester 1 activity plan (Gantt Chart)

For second semester, the following Gantt chart shows various activities planned for proposed system:

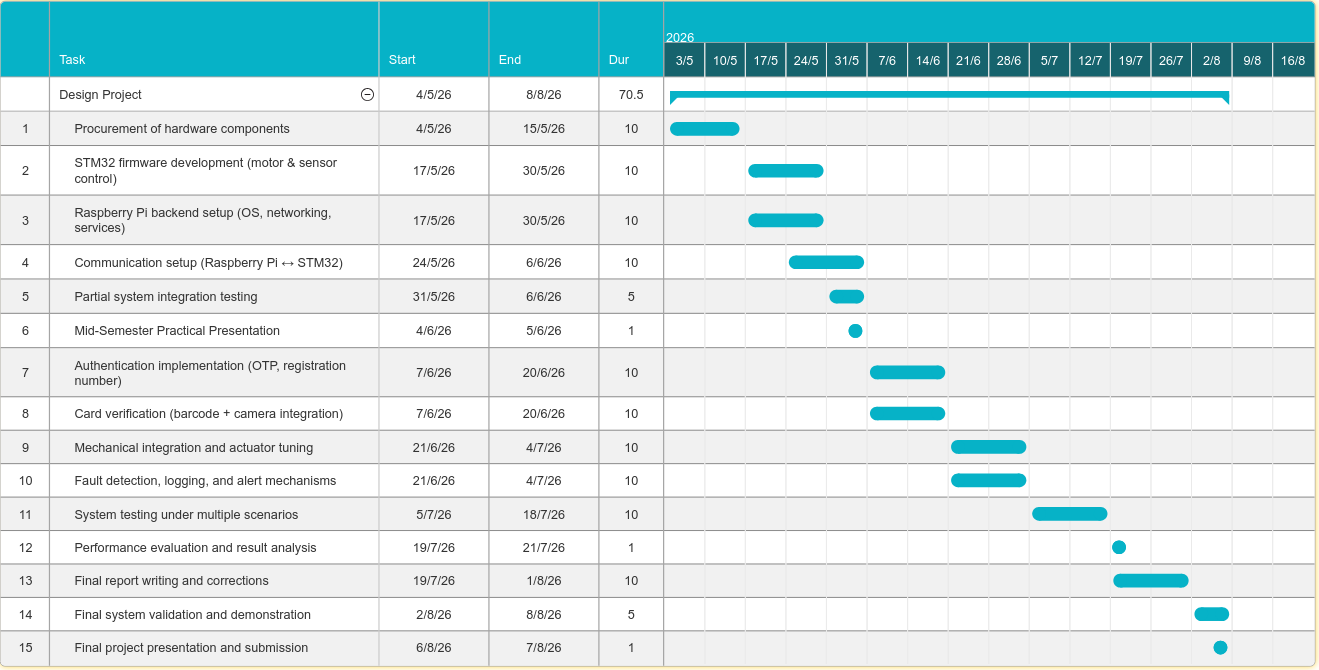
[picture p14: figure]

Figure 11: Semester 2 activity plan (Gantt Chart)

## 3.8 PROJECT BUDGET

From the local electronics shops visited, estimated total cost of the proposed system is computed as follows:

COMPONENT | ESTIMATED COST (TSh)
Raspberry Pi 5 (4GB) | 200,000
Low-level controller (STM32) | 60,000
Raspberry Pi Camera | 50,000
Keypad | 5,000
LCD Display | 20,000
Enclosure (mechanical parts) | 50,000
Actuators (Motors and their drivers) | 80,000
Sensors (Limit switches, IR sensors) | 20,000
TOTAL | 485,000

Table 1: Project Budget

# CHAPTER FOUR: SOFTWARE IMPLEMENTATION AND CIRCUIT SIMULATION

This chapter depicts a part of implementation done (software) for the Automated ID Card Issuance System and the circuit simulation of some of the components. Due to lack of package modules for simulation for high-level controller and low-level controller used in the system, only electrically-based circuits were simulated.

## 4.1 SOFTWARE IMPLEMENTATION

This sub-system implementation was done in a controlled Ubuntu environment prior to hardware integration. Ubuntu environment was preferred since it correlates well with the later project’s environment which is Raspberry Pi OS. The focus on this was development and testing of the computer vision module and back-end authentication system.

Along with Ubuntu development environment, other implementation environment included: python programming language, Open-CV library for image processing, Tesseract OCR engine for OCR detection, Fast API framework for back-end services and SQLite/PostgreSQL database for student records. These modules were all implemented locally to simulate the final system’s architecture.

Back-end authentication system is not fully implemented, and SMS gateway interface for OTP transmission and verification is not implemented at all.

For computer vision module, processes mentioned in chapter 3 above were implemented and the results are as follows:

- Image capturing was done by a phone camera and stored in the computer.
- Card detection and perspective correction, contour-based detection was implemented to identify quadrilateral shapes and the transformation was applied to improve OCR consistency by reducing distortions. Below are the results of card detection, green lines show verification:

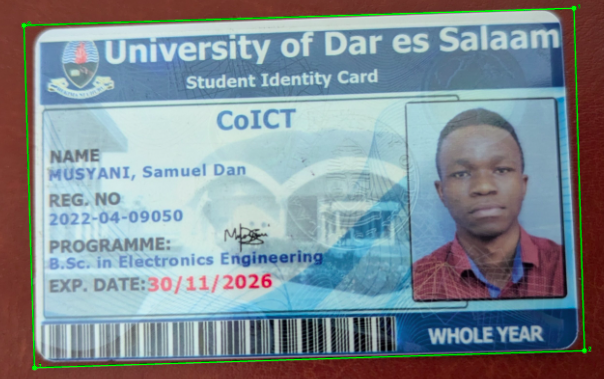
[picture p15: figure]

Figure 12: Sample card detected (green line shows detection)

- Anchor-based ROI localization, a known anchor label “NAME” within a corrected card image and isolate the region containing the registration number according to the relative offsets. The blue box shows the detection of the anchor label.

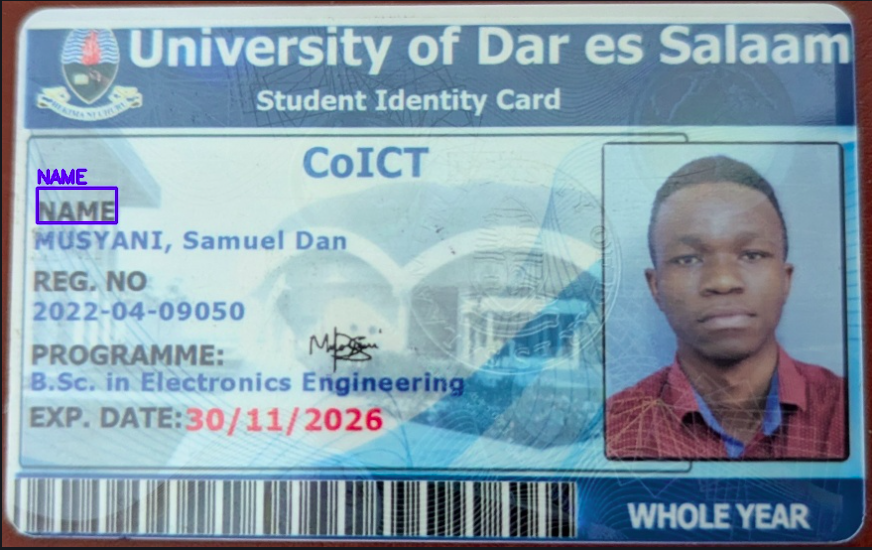
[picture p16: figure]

Figure 13: Anchor-ROI localization of sample card

- OCR extraction, validation and performance analysis, Tesseract OCR was used with prioritization of numeric recognition and validation of the extracted text against the institutional format. In addition to that, processing time and success message was extracted and logged into the system.

Figure 15: Text extraction and processing performances

## 4.2 CIRCUIT SIMULATION

### 4.2.1 REVERSE POLARITY CIRCUIT

Circuit simulation was done for electrical logic in the design using Proteus Design Suite (PDS). Power supply circuit which involved input protection with implementation of fuse and reverse polarity protection. This circuit simulation involved the use of MOSFET (P-channel) and a 15V Zener diode. The results for reverse polarity protection are as follows:

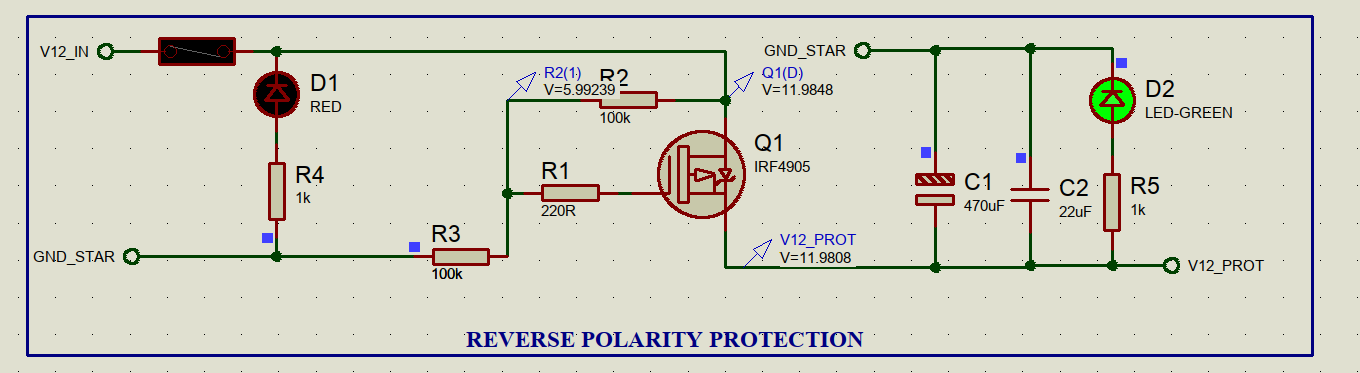
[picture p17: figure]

Figure 15: Correct input polarity

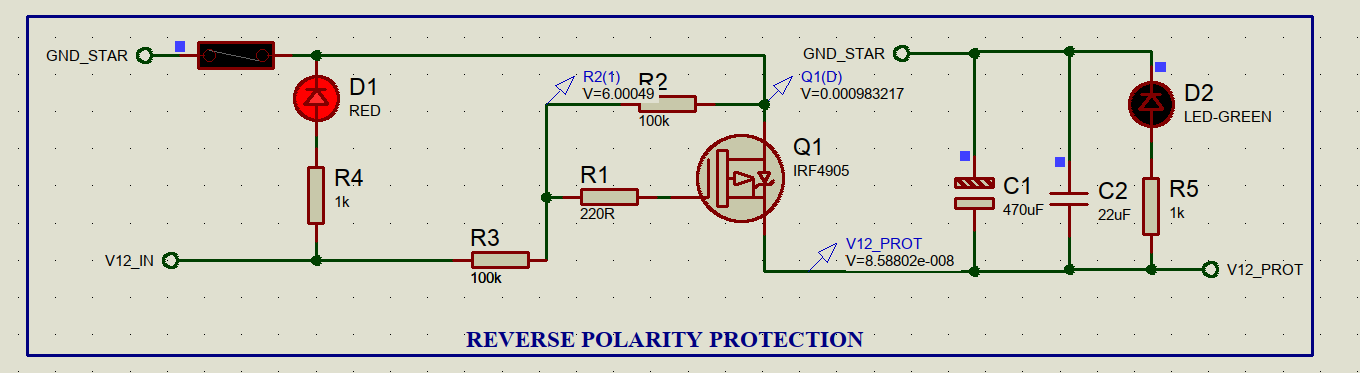
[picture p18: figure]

Figure 16: Wrong input polarity

As observed, in the correct polarity, the output node (V12_P) is set to 11.9808V which is expected. On the other side, the wrong polarity, the output node (V12_P) is set to 8.5588⁻⁸V which is very small close to zero. This means that the circuit’s reverse polarity protection works fine in the simulation.

Also, for the power supply, power rail separation was implemented to prevent interferences between the logic components and the motor parts. This is because the motor usually sink some various inrush currents which forms a problem to power sensitive components.

### 4.2.2 BUCK CONVERSION CIRCUITS

For LMZ23610 and TPSM82903, their simulation modules are not available in various simulation platforms. With other applications, no relevance of simulation results and the reality of the behaviour of such modules were recorded from the research. Therefore, WEBENCH Power Designer from Texas Instruments was used for design estimation on behaviours of the chosen modules.

For LMZ23610 module, there are two simulation done with that particular design circuit. The simulations are as explained below:

- At startup simulation; the module with its peripherals and external components connected is tested for peak currents and voltage and the overall behaviour of the module as shown below. The voltage rises at the power on moment will current slowly ramps up to 5A.

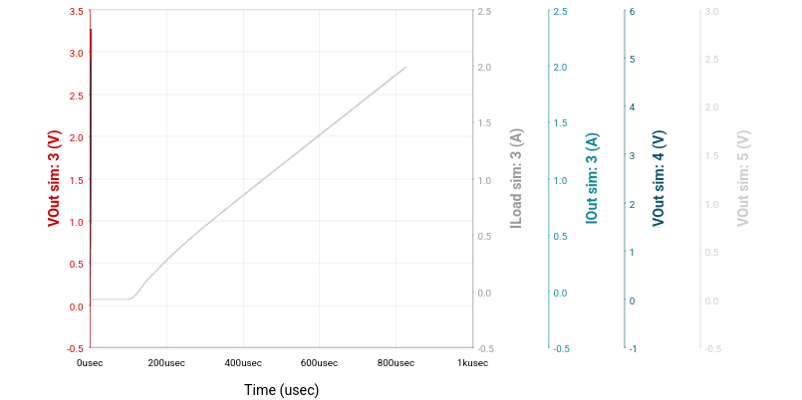
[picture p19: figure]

Figure 17: LMZ23610 simulation results at startup

- At steady state; the module was tested with steady state output condition, with clear observations on voltage descending to 5V exactly which is within the expected output ranges.

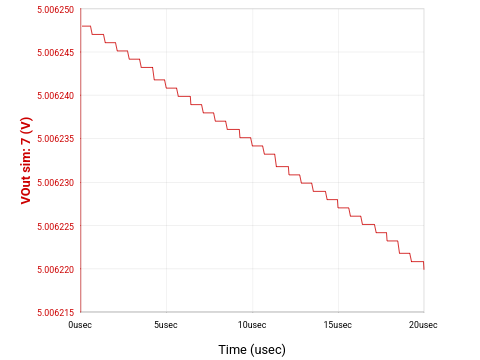
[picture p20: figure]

Figure 18: LMZ23610 simulation results at steady state

For TPSM82903 module also, there were two simulations done with that particular design circuit. The simulations are as explained below:

- At startup simulation; the module with its peripherals and external components connected is tested for peak currents and voltage and the overall behaviour of the module as shown below. The time to start giving out output voltage is controlled by the soft start pin which is usually connected to a capacitor, but in the designed schematic, it was not connected to ensure minimum start time as observed.

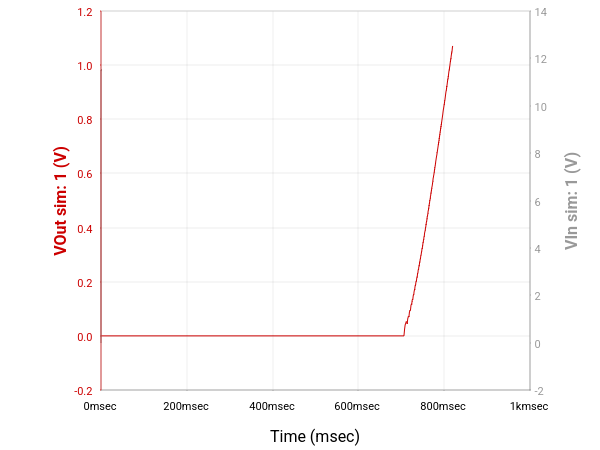
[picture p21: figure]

Figure 19: PTSM82903 simulation results at start up

- At load transient; the module was tested for transient at the load node. It is then observed in the simulation that as soon as the output voltage exceeds 3.6V, the currents drops significantly as this is a safety feature since the design served components of 3.3V only.

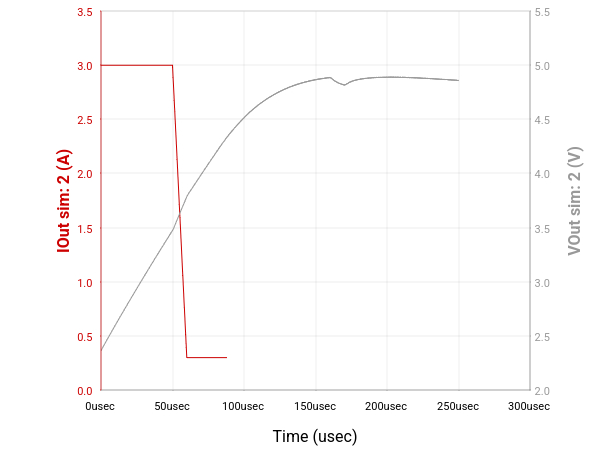
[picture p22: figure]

Figure 20: PTSM82903 simulation results at load transient

### 4.2.3 MOTOR DRIVER CIRCUIT SIMULATION

The designed schematic for custom motor driver using ULN2003A chip for driving a stepper motor was simulated using Proteus Design Suite (PDS) in order to observe and record the studied behaviour of the said module. The simulation was as follows:

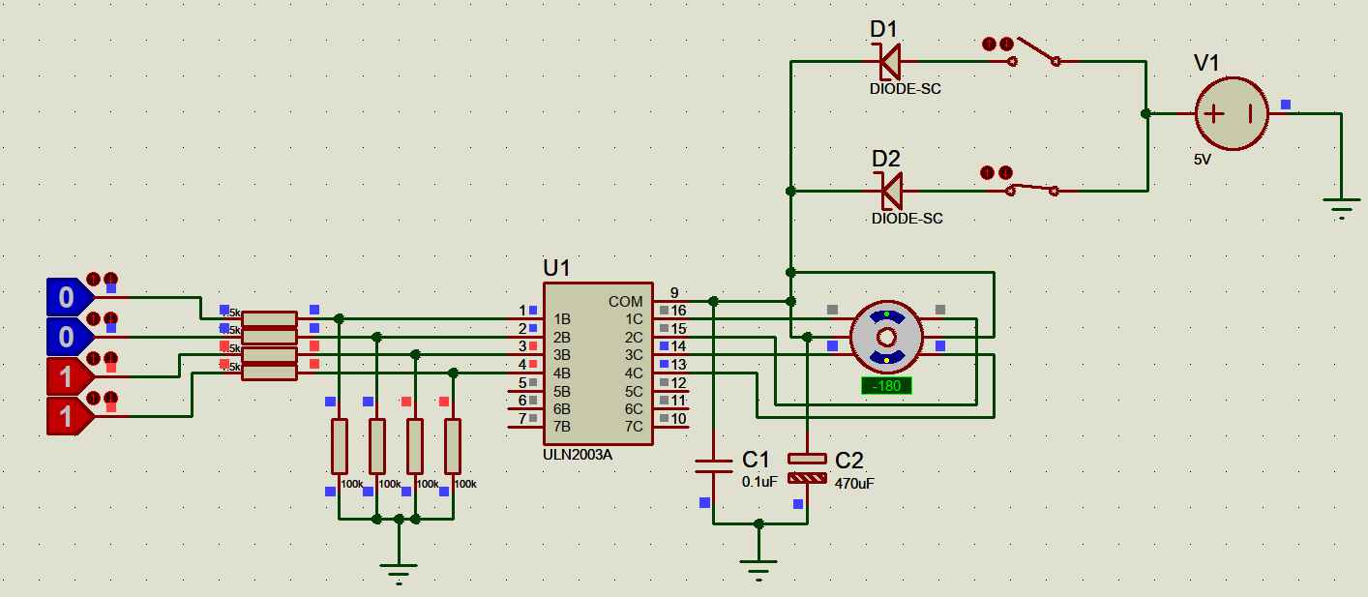
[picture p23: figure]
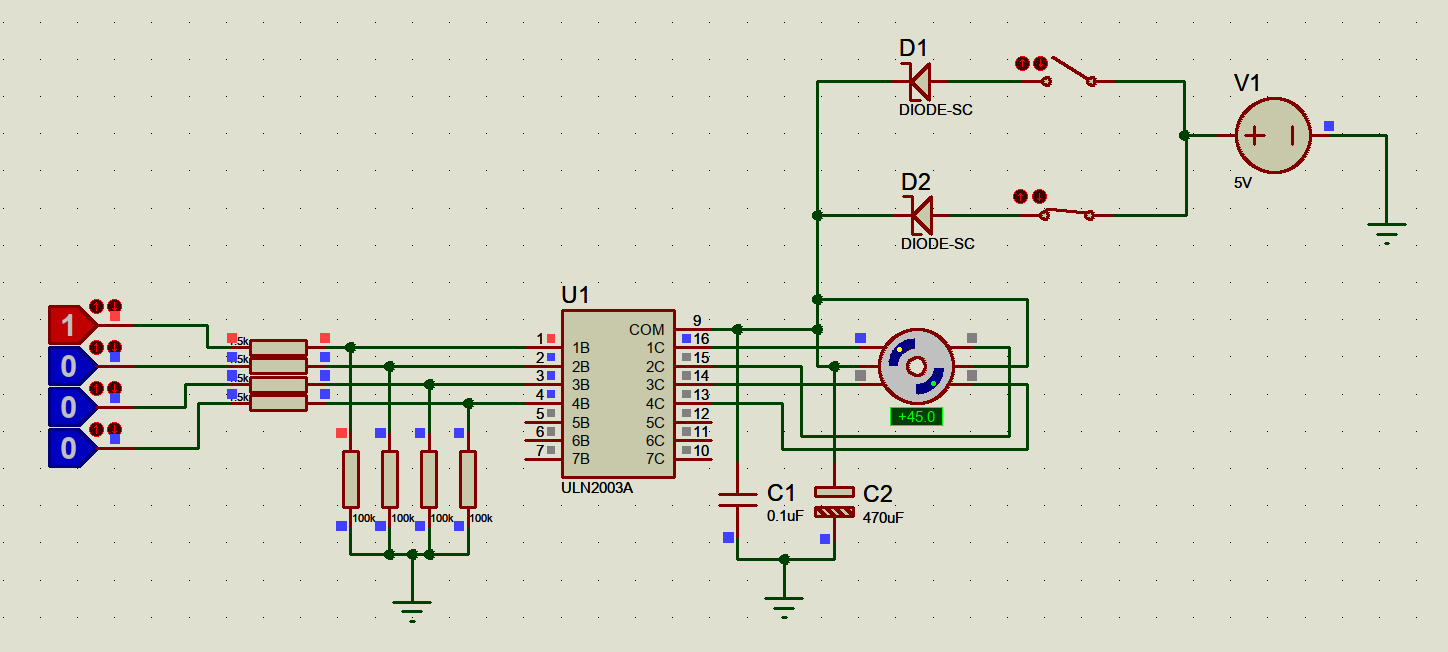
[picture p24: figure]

Figure 21: 0011 and 1000 test signals (from MCU) to motor driver

Since the motor driver will be driven by the STM32, the logic source signals were used to imitate the signals provided by the MCU at different intervals, and 0011 combination gave out -180° turn while 1000 combination gave out 45° turn on the stepper motor, according to the steps and respective angular displacement set. Thus, the connection of the motor driver circuit is electrically correct.

# CHAPTER FIVE: CONCLUSION

At the end of the first semester, the project’s implemented parts are mostly software and electrical hardware simulations. Software implementations were performed prior to their hardware environment (high-level controller) because the environment used (Linux) is highly compatible to the environment with which the software will run in (Raspberry Pi OS). On the next chapter of progress, hardware facilities are expected to be available for proper implementation of computer vision, and for implementing the authentication with the backend running in the mentioned high-level controller.

Electrical hardware simulations of various power circuit components were conducted, yielding results that match closely to the theoretical results in each of the simulations. Therefore, the next progress goal is to physically obtain the electronic components and build the circuits for power supply implementation. Additionally, logics and communication interfaces will be integrated together with enclosure design and the mechanics to sort and distribute ID cards to individual students.

# REFERENCES

- Ratnasri, Nilani & Sharmilan, Tharaga. (2021). Vending Machine Technologies: A Review Article. International Journal of Sciences: Basic and Applied Research (IJSBAR). 58. 160-166.
- Aman Prasad, Shraddha Kumar, Keshav Shriram, Prof. Dr. Vikram Mane, “IOT Based Pen Vending Machine”, Published in International Research Journal of Innovations in Engineering and Technology-IRJIET, Volume 8, Issue 3, pp 367-373, March 2024. Article DOI https://doi.org/10.47001/IRJIET/2024.803057
- Bai, Y., Hu, J., Liu, J., & Zhou, Q. (2012). Card transport device and ATM using same (U.S. Patent No. US8251282B2). U.S. Patent and Trademark Office.
- Instructables User “Joe_Squared”. (2017). DIY trading card dispenser project. Instructables.
- Peter Kibaya, Charles S Lubobya (2024) Design of a Multifactor Authentication System for Automated Teller Machines. 1: 1-17
- Xia, K., Fan, H., Huang, J., Wang, H., Ren, J., Jian, Q., & Wei, D. An Intelligent Self-Service Vending System for Smart Retail. Sensors, 21(10), 3560. https://doi.org/10.3390/s21103560

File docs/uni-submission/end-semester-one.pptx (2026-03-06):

## FINAL YEAR PROJECT PRESENTATION

PROGRESS STAGE: End of Semester 1
CANDIDATE: Musyani, Samuel Dan
SUPERVISOR: Dr. Hashim Iddi
PROJECT TITLE: Design and Implementation of an Automated ID Card Issuance System

## INTRODUCTION

- The project aims to ease ID card issuance process for registered students by developing a prototype of an automated system
- Registered students will be able to return their expired cards, and retrieve their valid ID cards for that particular academic year

## PROBLEM STATEMENT

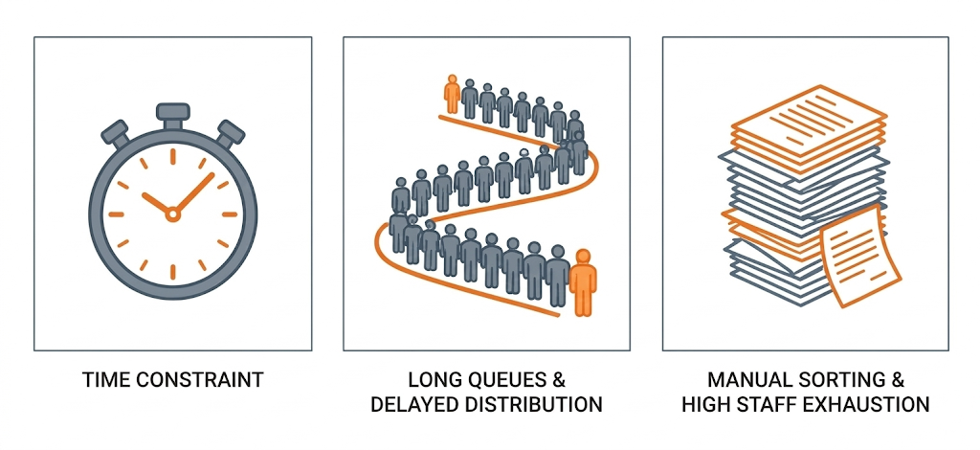
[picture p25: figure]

- With high student volumes, narrow administrative working window leads to long queues and delayed distribution

## PROPOSED SOLUTIONS

An automated card issuance system, with:

Automated reliable dispensing:
Sorts and distributes cards
24/7 with real-time control

Computer Vision:
Automated card details verification
for sorting and distribution

Secure Authentication:
OTP and PIN for student
verification

Audit logging:
Record all activities happening
for debugging and tracking

## OBJECTIVES

Main Objective:
- To design and implement an Automated ID card Issuance System
Specific Objectives:
- To implement robust authentication
- To implement an actuator control system
- To enforce security policy and audit logging

## SYSTEM ARCHITECTURE

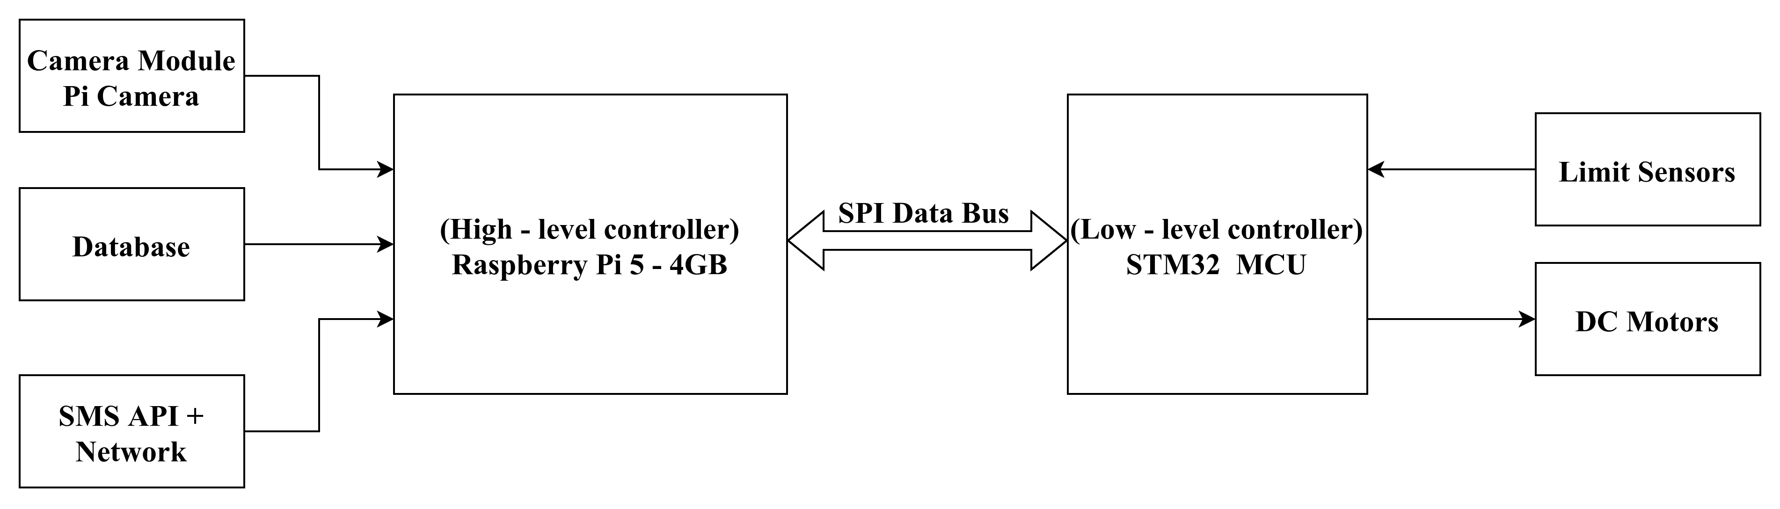
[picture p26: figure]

- High – level controller manages authentication, UI, database and computer vision while low – level controller manages real – time controls and sensor integration

## FUNCTIONAL WORKFLOW


## FUNCTIONAL WORKFLOW


## COMPUTER VISION PIPELINE


## CIRCUIT DESIGN AND SIMULATION

- Power separation rail design


- Separation is done to prevent inrush current (motors) interfering from logic components

## CIRCUIT DESIGN AND SIMULATION

- Reverse Polarity Protection Circuit


- Correct polarity connection allows connection to the output node
- Wrong polarity connection does not allow connection to the output node


## CIRCUIT DESIGN AND SIMULATION

- Motor driver circuit


- ULN2003A driver circuit was designed to drive stepper motors and simulation went as expected

## CONCLUSION

- Work done to date; system architecture design, computer vision pipeline, database creation, schematic design and electronic components’ simulation
- Next progress; authentication system, hardware components procurement, circuit integration and enclosure design and implementation

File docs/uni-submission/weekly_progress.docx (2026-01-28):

PROGRESS FOR WEEK 10

For week 10, I have referenced some existing projects with similar card or object dispensing activities. That highlighted two of the crucial part of my final year project which are: card acceptance mechanism (for accepting expired ID cards) and card sorting and storage system.

Starting with card acceptance mechanism, a pair of rollers driven with stepper motors is the most preferred approach due to its steps precision and ease interaction with the card’s properties. Stepper motor will also enhance placement of the card along with the Pi camera for barcode scanning.


Sketch for card acceptance mechanism

With card sorting and storage system, a combination of servo motor and a circular bin calculated with each slot to an assigned mapped number will function the best for my system. If the card is needed, the bin is rotated by the servo motor up to the calculated position and a card is taken/ejected from the bin.


An example of circular storage bin

In addition to the references, overview functional workflows; student’s side and staff’s side were as follows:


Functional workflow of the system – staff’s side.


Functional workflow of the system – student’s side

REFERENCES

- Bai, Y., Hu, J., Liu, J., & Zhou, Q. (2012). Card transport device and ATM using same (U.S. Patent No. US8251282B2). U.S. Patent and Trademark Office.
- Instructables User “Joe_Squared”. (2017). DIY trading card dispenser project. Instructables.

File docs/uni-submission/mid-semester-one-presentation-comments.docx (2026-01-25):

COMMENTS FROM MID-SEMESTER PRESENTATION

Comment: Identify what resource you require from the University.

Answer: University database is needed for verification of various student’s information, but since it is a very critical part with high risk of vulnerability, a mock database similar to it will be used.

Comment: Determine whether you will use University provided equipments or external alternatives.

Answer: A small sample student’s expired ID cards (about 5) will be needed for implementation of my final year project. Other hardware equipments will be from external alternatives.

Comment: Define the logic and flow for verification codes, especially handling two-factor verification.

Answer: An extra layer of PIN, that a first user puts in. Therefore, One Time Password (OTP) and PIN set by the student will be enough for two-factor authentication.

Comment : Address potential challenges in sorting process.

Answer: Main challenge in sorting process will be maneuvering of the cards through store bins to the indicated place for card ejection or accepting.

Comment: Ensure the final product can reliably sort out the particular card from a group of cards.

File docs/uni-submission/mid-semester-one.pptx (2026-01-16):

## FINAL YEAR PROJECT PROGRESS PRESENTATION

CANDIDATE: | Musyani, Samuel Dan Reg No. 2022 – 04 – 09050
SUPERVISORS: | Dr. Hashim Iddi
PROJECT TITLE: | Design and Implementation of an Automated ID Card Issuance System

## Introduction

- The project aims to develop a prototype for an Automated Card Issuance System to streamline the collection of pre-printed ID Cards for registered students.
- Registered students will be able to return their expired cards and retrieve their valid ID cards for that particular academic year.

## Problem Statement

The current ID Card Issuance process for registered students at the University of Dar es Salaam faces long waiting period, narrow working windows and staff exhaustion due to large number of students

## Proposed Solution

An automated card issuance system for secure, on-demand card retrieval

Automated reliable dispensing:
Sorts and distributes ID cards 24/7

Audit Logging:
Records all activities happening for debugging and tracking

Secure Authentication:
SMS (OTP) for student verification

Real-time integrated control:
Micro-controller to control actuators in real-time

## Objectives

Main Objective
- To design and implement an Automated ID Card Issuance System for students’ pre-printed ID Cards
Specific Objectives
i. To implement a reliable actuator control system
ii. To implement authentication application
iii. To implement activity logging
iv. To enforce security policy
v. System performance evaluation

## Related Projects

- Automatic and Smart Vending Systems: self-service, cashless payment (IoT), and object detection (image processing).
- ATM with authentication and security: multi-factor approaches, like OTPs and biometrics to enhance security in automated environments.

## Methodology – System architecture

The proposed system uses dual-controller architecture for robust operation.

High-level Controller:
Manages UI, network, SMS OTP, database access, computer vision, logging and commands to real-time controller

Real-time Controller:
Directly controls motors, safety monitoring and status reporting to high-level controller.

## Methodology - Workflow

Preload Phase:
Staff inserts cards, cards are scanned and mapped to storage

Notification Phase:
High-level controller sends SMS that cards are ready

Retrieval Phase:
Student returns card, enters OTP, gets card and logs.

## Conclusion

The proposed project shows that an Automated ID Card Issuance System can streamline card distribution and collection for University students.

## THANK YOU!

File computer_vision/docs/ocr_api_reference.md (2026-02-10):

# OCR API Reference

## Module: computer_vision

### scan_student_id_card(image, config=None)

Scans a card image and returns a structured OCR result.

### Parameters

- `image`: BGR image (NumPy array)
- `config` (optional): config dict override

### Scans

```bash
{
  'success': bool,
  'student_id': str | None,
  'confidence': float,
  'method': str,
  'error': str | None,
  'processing_time_ms': float
}
```

## Pipeline: CardOCRPipeline

Located at [computer_vision/pipeline/ocr_pipeline.py](computer_vision/pipeline/ocr_pipeline.py).

### scan_card(image)

Runs detection → correction → ROI → OCR → validation.

## Notes

- Configure OCR settings in [computer_vision/config/ocr_config.py](computer_vision/config/ocr_config.py).
- Use [examples/basic_usage.py](examples/basic_usage.py) for a minimal example.

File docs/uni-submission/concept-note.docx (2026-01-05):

CONCEPT NOTE

Proposed title: Automated self-service ID card issuance dispenser.

Problem Statement: The current student ID card issuance process involves a waiting period of approximately one week after registration due to delayed card availability in the individual’s college. After release, the card collection also requires students to queue and sort a bunch of ID cards. So, for a high volume of students, the staff responsible suffers significant work strain. On top of that, fixed hours also hinder the sorting capacity of students' issuance per time. As a result, card issuance for registered students takes up to several days, which may bring inconvenience to students.

Proposed solution: Design of an automated embedded system for students’ ID card issuance aimed at reducing delays, long queues, and staff dependency. The software handles user interaction, authentication, logging, and back-end validation of students’ information, while the hardware comprises of embedded unit with user input and card dispensing mechanisms. This is aimed to work 24/7 with efficiency and reliability for service delivery for a large student group.

Main Objective: To design and implement an automated self-service ID card issuance dispenser.

Specific Objectives:

- To design and implement embedded control hardware (micro-controller based system controlling all activities).
- To integrate a card-sorting module with the embedded hardware.
- To establish back-end connection for identity verification.
- Provide user interaction and feedback mechanisms.
- Implement secure card issuance, logging (one card per semester) and handle incomplete issuances.
- Handle failures and recovery (power, module malfunctions and communication errors).
- To test a fully implemented prototype.

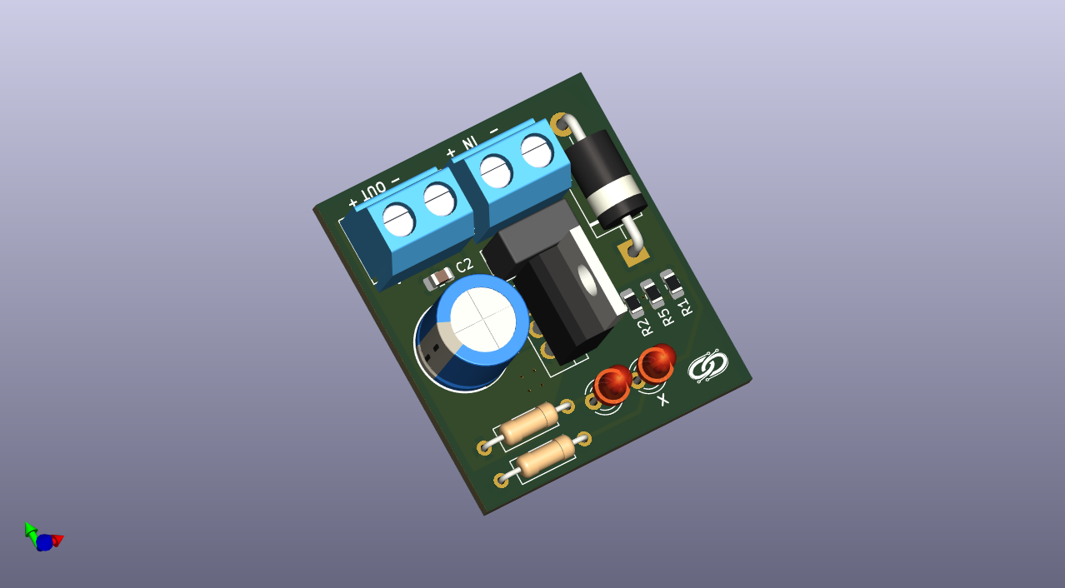
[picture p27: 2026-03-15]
hardware/3d/reverse_polarity.png

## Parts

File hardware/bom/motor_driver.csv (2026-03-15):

Id | Designator | Footprint | Quantity | Designation | Supplier and ref
1 | U1 | DIP-16_W7.62mm_Socket | 1 | ULN2003A
2 | R8,R7,R6,R5 | R_0805_2012Metric_Pad1.20x1.40mm_HandSolder | 4 | 100k
3 | R4,R2,R1 | R_0805_2012Metric_Pad1.20x1.40mm_HandSolder | 3 | 1.5k
4 | R3 | R_0805_2012Metric_Pad1.20x1.40mm_HandSolder | 1 | 1,5k
5 | J4 | PinHeader_1x05_P2.54mm_Vertical | 1 | FROM_MCU
6 | J3 | JST_XH_B5B-XH-A_1x05_P2.50mm_Vertical | 1 | TO_MOTOR
7 | J2 | PinHeader_1x02_P2.54mm_Vertical | 1 | 5V_IN
8 | J1 | BarrelJack_GCT_DCJ200-10-A_Horizontal | 1 | 5V_ADAPTER
9 | D2,D1 | D_DO-201AD_P15.24mm_Horizontal | 2 | Schottky
10 | C2 | CP_Radial_D10.0mm_P5.00mm | 1 | 470uF
11 | C1 | C_0805_2012Metric_Pad1.18x1.45mm_HandSolder | 1 | 0.1uF

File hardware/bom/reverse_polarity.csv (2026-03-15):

Id | Designator | Footprint | Quantity | Designation | Supplier and ref
1 | F1 | FUSRR508W60L835T400H810 | 1 | 0697H9100-01
2 | J2 | CUI_TB002-500-02BE | 1 | 12V_IN
3 | J1 | CUI_TB002-500-02BE | 1 | 12V_OUT
4 | Q1 | TO-220-3_Vertical | 1 | IRF4905
5 | R2 | R_0805_2012Metric_Pad1.20x1.40mm_HandSolder | 1 | 220R
6 | R3,R4 | R_Axial_DIN0207_L6.3mm_D2.5mm_P10.16mm_Horizontal | 2 | 1k
7 | C2 | C_0805_2012Metric_Pad1.18x1.45mm_HandSolder | 1 | 22uF
8 | C1 | CP_Radial_D10.0mm_P5.00mm | 1 | 470uF
9 | R1,R5 | R_0805_2012Metric_Pad1.20x1.40mm_HandSolder | 2 | 100k
10 | D1 | LED_D3.0mm | 1 | RED
11 | D3 | D_DO-201AE_P15.24mm_Horizontal | 1 | TVS
12 | D2 | LED_D3.0mm | 1 | GREEN

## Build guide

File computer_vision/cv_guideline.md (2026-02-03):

# Computer Vision Implementation Guideline

## Project: ID Card Kiosk - Computer Vision Module

**Purpose:** Complete task list for implementing the barcode scanning system for automated ID card dispensing.

**Estimated Total Time:** 3-4 weeks (working part-time)

---

## Phase 1: Environment Setup & Hardware Preparation

**Goal:** Get all tools and hardware ready for CV development

### Task 1.1: Install Required Software

- [x] Update Raspberry Pi OS to latest version
- [x] Install Python 3.9 or higher
- [x] Install OpenCV library (`python3-opencv`)
- [x] Install pyzbar library for barcode reading
- [x] Install Pillow for image handling
- [x] Install picamera2 (if using Pi Camera Module)
- [x] Verify all installations with version checks

**Success Criteria:** All libraries import without errors in Python

**Estimated Time:** 1 hour

---

### Task 1.2: Acquire and Connect Camera Hardware

- [ ] Purchase/obtain Raspberry Pi Camera Module 3 (or USB webcam)
- [ ] Physically mount camera to Raspberry Pi
- [ ] Enable camera interface in Raspberry Pi configuration
- [ ] Test camera connection with basic capture command
- [ ] Verify image quality and focus

**Success Criteria:** Camera captures clear images, saves to file successfully

**Estimated Time:** 2 hours

---

### Task 1.3: Set Up Development Environment

- [x] Create project directory structure (as defined)
- [x] Initialize Git repository (optional but recommended)
- [x] Create virtual environment for Python dependencies
- [x] Create `requirements.txt` file with all dependencies
- [x] Set up IDE/editor (VS Code, Thonny, or preferred)

**Success Criteria:** Directory structure matches specification, can run Python scripts from project root

**Estimated Time:** 30 minutes

---

### Task 1.4: Prepare Test Data

- [x] Obtain 5-10 sample ID cards (with permission) OR create mock cards with barcodes
- [ ] Photograph sample cards at various angles (0°, 15°, 30°)
- [x] Photograph cards under different lighting conditions
- [x] Save images to `data/sample_barcodes/` directory
- [ ] Document each image (filename format: `card_ID_angle_lighting.jpg`)

**Success Criteria:** At least 20 test images captured and organized

**Estimated Time:** 2 hours

---

## Phase 2: Core Functionality - Image Capture

**Goal:** Implement reliable camera interface

### Task 2.1: Create Camera Configuration

- [ ] Define camera parameters in `config/camera_config.py`
- [ ] Set resolution (start with 1280x720)
- [ ] Set frame rate (15-30 fps)
- [ ] Define exposure and brightness defaults
- [ ] Add camera type selection (Pi Camera vs USB)

**Success Criteria:** Configuration file loads without errors, parameters are accessible

**Estimated Time:** 30 minutes

---

### Task 2.2: Implement Basic Camera Interface

- [ ] Create `image_capture.py` file
- [ ] Write function to initialize camera based on type
- [ ] Write function to capture single frame
- [ ] Write function to save captured frame to file
- [ ] Write function to release camera resources
- [ ] Add error handling for camera connection failures

**Success Criteria:** Can capture and save image programmatically

**Estimated Time:** 2 hours

---

### Task 2.3: Test Camera Module

- [ ] Create `tests/test_image_capture.py`
- [ ] Write test for camera initialization
- [ ] Write test for frame capture
- [ ] Write test for camera release
- [ ] Run all tests and verify they pass
- [ ] Fix any bugs discovered

**Success Criteria:** All camera tests pass, no resource leaks

**Estimated Time:** 1 hour

---

## Phase 3: Image Preprocessing

**Goal:** Prepare images for reliable barcode detection

### Task 3.1: Implement Basic Preprocessing Functions

- [x] Create `image_utils.py` file
- [x] Write function to convert image to grayscale
- [x] Write function to resize image (maintain aspect ratio)
- [x] Write function to crop image to region of interest
- [ ] Write function to save debug images with annotations

**Success Criteria:** Each function works independently with test images

**Estimated Time:** 2 hours

---

### Task 3.2: Implement Advanced Preprocessing

- [ ] Add Gaussian blur function (reduce noise)
- [ ] Add adaptive thresholding function (handle lighting variations)
- [ ] Add morphological operations (close gaps in barcode lines)
- [ ] Add contrast enhancement function
- [ ] Test each function on sample images, compare before/after

**Success Criteria:** Preprocessing improves barcode visibility in poor-quality images

**Estimated Time:** 3 hours

---

### Task 3.3: Create Preprocessing Pipeline

- [ ] Write function that chains preprocessing steps
- [ ] Make pipeline configurable (enable/disable specific steps)
- [ ] Add timing measurements to identify slow operations
- [ ] Optimize processing order for best results
- [ ] Document which preprocessing helps which image problems

**Success Criteria:** Pipeline processes image in under 200ms

**Estimated Time:** 2 hours

---

### Task 3.4: Test Image Utilities

- [ ] Create `tests/test_image_utils.py`
- [ ] Test each preprocessing function individually
- [ ] Test full pipeline with various image qualities
- [ ] Verify output images are valid
- [ ] Run all tests and fix bugs

**Success Criteria:** All preprocessing tests pass

**Estimated Time:** 1.5 hours

---

## Phase 4: Barcode Detection & Decoding

**Goal:** Reliably find and read barcodes from ID cards

### Task 4.1: Implement Basic Barcode Detection

- [x] Create `barcode_reader.py` file
- [x] Write function to detect barcode location in image (using pyzbar)
- [x] Extract bounding box coordinates (x, y, width, height)
- [x] Return confidence score if available
- [x] Handle case where no barcode is found

**Success Criteria:** Detects barcode location in 90%+ of test images

**Estimated Time:** 2 hours

---

### Task 4.2: Implement Barcode Decoding

- [x] Write function to decode barcode data from image
- [x] Extract barcode string (student ID)
- [x] Extract barcode type (Code128, QR, etc.)
- [x] Validate decoded data format
- [x] Handle decoding failures gracefully

**Success Criteria:** Decodes barcode data correctly from clear images

**Estimated Time:** 1.5 hours

---

### Task 4.3: Combine Detection + Decoding

- [ ] Write combined function: `scan_card(image)`
- [ ] Integrate preprocessing pipeline before detection
- [ ] Return structured result: `{barcode_id, type, bbox, confidence}`
- [ ] Add retry logic with different preprocessing (if first attempt fails)
- [ ] Log all scan attempts and results

**Success Criteria:** Single function call reliably returns barcode data

**Estimated Time:** 2 hours

---

### Task 4.4: Handle Edge Cases

- [ ] Handle multiple barcodes in single image
- [ ] Handle partially visible barcodes
- [ ] Handle damaged/worn barcodes
- [ ] Add minimum confidence threshold
- [ ] Implement maximum retry attempts (3 retries)

**Success Criteria:** System handles edge cases without crashing

**Estimated Time:** 2 hours

---

### Task 4.5: Test Barcode Reader

- [ ] Create `tests/test_barcode_reader.py`
- [ ] Test detection with clear images
- [ ] Test detection with poor lighting
- [ ] Test detection with angled cards
- [ ] Test decoding accuracy
- [ ] Test edge case handling
- [ ] Run all tests and fix bugs

**Success Criteria:** 95%+ detection rate on test dataset

**Estimated Time:** 2 hours

---

## Phase 5: Error Handling & Robustness

**Goal:** Make system resilient to failures

### Task 5.1: Define Custom Exceptions

- [x] Create `exceptions.py` file
- [x] Define `BarcodeNotFoundError` exception
- [ ] Define `MultipleBarcodeError` exception
- [ ] Define `BarcodeDecodeError` exception
- [ ] Define `CameraError` exception
- [ ] Add descriptive error messages for each

**Success Criteria:** All custom exceptions defined and importable

**Estimated Time:** 30 minutes

---

### Task 5.2: Integrate Exception Handling

- [ ] Update `barcode_reader.py` to raise appropriate exceptions
- [ ] Update `image_capture.py` to raise `CameraError` on failures
- [ ] Add try-except blocks around all CV operations
- [ ] Log exceptions with full context (timestamp, image path, error details)
- [ ] Test that exceptions propagate correctly to caller

**Success Criteria:** System provides clear error messages for all failure modes

**Estimated Time:** 2 hours

---

### Task 5.3: Implement Retry Logic

- [ ] Create retry wrapper function (max 3 attempts)
- [ ] Add progressive backoff (wait 0.5s between retries)
- [ ] Try different preprocessing on each retry
- [ ] Log each retry attempt
- [ ] Return detailed failure report after exhausting retries

**Success Criteria:** System automatically recovers from temporary failures

**Estimated Time:** 1.5 hours

---

## Phase 6: System Integration & Testing

**Goal:** Integrate CV module with main system

### Task 6.1: Create Public API

- [ ] Update `computer_vision/__init__.py`
- [ ] Export main functions: `scan_card()`, `verify_card()`
- [ ] Create simple usage examples
- [ ] Document expected input/output formats
- [ ] Version the API (v1.0)

**Success Criteria:** High-level controller can import and use CV functions easily

**Estimated Time:** 1 hour

---

### Task 6.2: Integration with Database

- [ ] Define data structure for card mapping: `{slot_index: barcode_id}`
- [ ] Write function to scan card and return mapping data
- [ ] Write function to verify card matches expected barcode
- [ ] Add database logging for all scan operations
- [ ] Test database writes and reads

**Success Criteria:** CV scan results successfully stored in database

**Estimated Time:** 2 hours

---

### Task 6.3: Create End-to-End Test

- [ ] Simulate staff card loading workflow
- [ ] Scan 10 cards, store mappings
- [ ] Simulate student retrieval workflow
- [ ] Verify each card against expected barcode
- [ ] Measure total time for complete workflow
- [ ] Document any failures or issues

**Success Criteria:** Complete workflow executes without manual intervention

**Estimated Time:** 2 hours

---

### Task 6.4: Performance Benchmarking

- [ ] Measure average scan time (target: <500ms)
- [ ] Measure detection success rate (target: >95%)
- [ ] Measure false positive rate (target: <2%)
- [ ] Test under different lighting conditions
- [ ] Test with 50+ different barcode images
- [ ] Document results in `docs/performance_benchmarks.md`

**Success Criteria:** System meets or exceeds performance targets

**Estimated Time:** 3 hours

---

## Phase 7: Camera Calibration & Optimization

**Goal:** Maximize accuracy and speed

### Task 7.1: Camera Calibration

- [ ] Print checkerboard calibration pattern (9x6 or similar)
- [ ] Capture 20+ images of checkerboard at different angles
- [ ] Save images to `data/calibration_images/`
- [ ] Run OpenCV calibration algorithm
- [ ] Extract intrinsic matrix and distortion coefficients
- [ ] Save calibration data to `config/calibration_data.json`

**Success Criteria:** Camera calibration completes, distortion correction works

**Estimated Time:** 3 hours

---

### Task 7.2: Apply Calibration to Pipeline

- [ ] Load calibration data on system startup
- [ ] Apply lens distortion correction to captured images
- [ ] Compare barcode detection before/after correction
- [ ] Measure performance improvement
- [ ] Make calibration optional (config flag)

**Success Criteria:** Calibrated system detects barcodes more reliably at angles

**Estimated Time:** 2 hours

---

### Task 7.3: Optimize Processing Speed

- [ ] Profile code to find bottlenecks (use cProfile)
- [ ] Reduce image resolution if possible (test 640x480)
- [ ] Process only region of interest (crop before processing)
- [ ] Cache preprocessed images if multiple operations needed
- [ ] Optimize preprocessing pipeline order
- [ ] Measure speed improvement

**Success Criteria:** Processing time reduced by 30%+ without accuracy loss

**Estimated Time:** 3 hours

---

## Phase 8: Documentation & Deployment Prep

**Goal:** Prepare system for deployment and handover

### Task 8.1: Write Setup Guide

- [ ] Create `docs/cv_setup_guide.md`
- [ ] Document camera installation procedure
- [ ] Document lighting setup requirements
- [ ] Document calibration procedure
- [ ] Include troubleshooting section
- [ ] Add photos/diagrams of proper setup

**Success Criteria:** Someone unfamiliar with the project can set up CV system using guide

**Estimated Time:** 3 hours

---

### Task 8.2: Create API Reference

- [ ] Document all public functions in `__init__.py`
- [ ] Include function signatures, parameters, return values
- [ ] Add usage examples for each function
- [ ] Document all custom exceptions
- [ ] Explain configuration options
- [ ] Save as `docs/cv_api_reference.md`

**Success Criteria:** Complete API documentation available

**Estimated Time:** 2 hours

---

### Task 8.3: Final System Validation

- [ ] Run all unit tests, ensure 100% pass
- [ ] Run integration tests with real hardware
- [ ] Test with 100+ barcode scans
- [ ] Verify error handling works correctly
- [ ] Test recovery from camera disconnection
- [ ] Document any known limitations

**Success Criteria:** System validated and ready for deployment

**Estimated Time:** 3 hours

---

### Task 8.4: Code Cleanup & Review

- [ ] Remove debug print statements
- [ ] Remove unused imports
- [ ] Add docstrings to all functions
- [ ] Format code with Black or autopep8
- [ ] Run linter (pylint) and fix issues
- [ ] Update `requirements.txt` with exact versions

**Success Criteria:** Code is clean, documented, and follows Python best practices

**Estimated Time:** 2 hours

---

## Phase 9: Optional Enhancements

**Goal:** Additional features if time permits

### Task 9.1: Add Logging Dashboard (Optional)

- [ ] Create simple visualization of scan success/failure rates
- [ ] Display average processing time
- [ ] Show most common failure modes
- [ ] Generate daily/weekly reports

**Estimated Time:** 4 hours

---

### Task 9.2: Implement Card Quality Check (Optional)

- [ ] Detect if card is damaged or defaced
- [ ] Check if barcode area is obscured
- [ ] Warn staff about low-quality cards during mapping
- [ ] Log quality metrics

**Estimated Time:** 3 hours

---

### Task 9.3: Add Multi-Threading (Optional)

- [ ] Separate camera capture and image processing into different threads
- [ ] Implement frame buffer for continuous capture
- [ ] Reduce latency between trigger and result
- [ ] Test thread safety

**Estimated Time:** 4 hours

---

## Completion Checklist

**Minimum Viable Product (MVP):**

- [ ] All Phase 1-6 tasks completed
- [ ] System scans barcodes reliably (>90% success rate)
- [ ] Error handling works correctly
- [ ] Integration with database functional
- [ ] Basic documentation complete

**Full Production System:**

- [ ] All Phase 1-8 tasks completed
- [ ] Camera calibrated and optimized
- [ ] Comprehensive documentation available
- [ ] System validated with real hardware
- [ ] Performance meets all targets

**Enhanced System (If Time Allows):**

- [ ] Phase 9 optional tasks completed
- [ ] Additional features implemented
- [ ] Advanced error recovery mechanisms

---

## Progress Tracking

**Week 1:** Phases 1-2 (Setup + Basic Capture)  
**Week 2:** Phases 3-4 (Preprocessing + Barcode Reading)  
**Week 3:** Phases 5-6 (Error Handling + Integration)  
**Week 4:** Phases 7-8 (Calibration + Documentation)

---

## Notes

- Each task should be marked complete only when success criteria are met
- If stuck on a task for >4 hours, document the blocker and seek help
- Test frequently - don't wait until end to discover issues
- Prioritize reliability over speed initially
- Document decisions and trade-offs as you go

---

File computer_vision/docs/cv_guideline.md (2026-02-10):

# Computer Vision Implementation Guideline

## Project: ID Card Kiosk - Computer Vision Module

**Purpose:** Complete task list for implementing the OCR-based ID detection system for automated ID card dispensing.

**Estimated Total Time:** 3-4 weeks (working part-time)

---

## Phase 1: Environment Setup & Hardware Preparation

**Goal:** Get all tools and hardware ready for CV development

### Task 1.1: Install Required Software

- [x] Update Raspberry Pi OS to latest version
- [x] Install Python 3.9 or higher
- [x] Install OpenCV library (`python3-opencv`)
- [x] Install pytesseract library for OCR reading
- [x] Install Pillow for image handling
- [x] Install picamera2 (if using Pi Camera Module)
- [x] Verify all installations with version checks

**Success Criteria:** All libraries import without errors in Python

**Estimated Time:** 1 hour

---

### Task 1.2: Acquire and Connect Camera Hardware

- [ ] Purchase/obtain Raspberry Pi Camera Module 3 (or USB webcam)
- [ ] Physically mount camera to Raspberry Pi
- [ ] Enable camera interface in Raspberry Pi configuration
- [ ] Test camera connection with basic capture command
- [ ] Verify image quality and focus

**Success Criteria:** Camera captures clear images, saves to file successfully

**Estimated Time:** 2 hours

---

### Task 1.3: Set Up Development Environment

- [x] Create project directory structure (as defined)
- [x] Initialize Git repository (optional but recommended)
- [x] Create virtual environment for Python dependencies
- [x] Create `requirements.txt` file with all dependencies
- [x] Set up IDE/editor (VS Code, Thonny, or preferred)

**Success Criteria:** Directory structure matches specification, can run Python scripts from project root

**Estimated Time:** 30 minutes

---

### Task 1.4: Prepare Test Data

- [x] Obtain 5-10 sample ID cards (with permission)
- [ ] Photograph sample cards at various angles (0°, 15°, 30°)
- [x] Photograph cards under different lighting conditions
- [x] Save images to `data/test_cards/` directory
- [ ] Document each image (filename format: `card_ID_angle_lighting.jpg`)

**Success Criteria:** At least 20 test images captured and organized

**Estimated Time:** 2 hours

---

## Phase 2: Core Functionality - Image Capture

**Goal:** Implement reliable camera interface

### Task 2.1: Create Camera Configuration

- [ ] Define camera parameters in `config/camera_config.py`
- [ ] Set resolution (start with 1280x720)
- [ ] Set frame rate (15-30 fps)
- [ ] Define exposure and brightness defaults
- [ ] Add camera type selection (Pi Camera vs USB)

**Success Criteria:** Configuration file loads without errors, parameters are accessible

**Estimated Time:** 30 minutes

---

### Task 2.2: Implement Basic Camera Interface

- [ ] Create `image_capture.py` file
- [ ] Write function to initialize camera based on type
- [ ] Write function to capture single frame
- [ ] Write function to save captured frame to file
- [ ] Write function to release camera resources
- [ ] Add error handling for camera connection failures

**Success Criteria:** Can capture and save image programmatically

**Estimated Time:** 2 hours

---

### Task 2.3: Test Camera Module

- [ ] Create `tests/test_image_capture.py`
- [ ] Write test for camera initialization
- [ ] Write test for frame capture
- [ ] Write test for camera release
- [ ] Run all tests and verify they pass
- [ ] Fix any bugs discovered

**Success Criteria:** All camera tests pass, no resource leaks

**Estimated Time:** 1 hour

---

## Phase 3: Image Preprocessing

**Goal:** Prepare images for reliable OCR detection

### Task 3.1: Implement Basic Preprocessing Functions

- [x] Create `image_utils.py` file
- [x] Write function to convert image to grayscale
- [x] Write function to resize image (maintain aspect ratio)
- [x] Write function to crop image to region of interest
- [ ] Write function to save debug images with annotations

**Success Criteria:** Each function works independently with test images

**Estimated Time:** 2 hours

---

### Task 3.2: Implement Advanced Preprocessing

- [ ] Add Gaussian blur function (reduce noise)
- [ ] Add adaptive thresholding function (handle lighting variations)
- [ ] Add morphological operations (enhance text lines and reduce noise)
- [ ] Add contrast enhancement function
- [ ] Test each function on sample images, compare before/after

**Success Criteria:** Preprocessing improves text visibility in poor-quality images

**Estimated Time:** 3 hours

---

### Task 3.3: Create Preprocessing Pipeline

- [ ] Write function that chains preprocessing steps
- [ ] Make pipeline configurable (enable/disable specific steps)
- [ ] Add timing measurements to identify slow operations
- [ ] Optimize processing order for best results
- [ ] Document which preprocessing helps which image problems

**Success Criteria:** Pipeline processes image in under 200ms

**Estimated Time:** 2 hours

---

### Task 3.4: Test Image Utilities

- [ ] Create `tests/test_image_utils.py`
- [ ] Test each preprocessing function individually
- [ ] Test full pipeline with various image qualities
- [ ] Verify output images are valid
- [ ] Run all tests and fix bugs

**Success Criteria:** All preprocessing tests pass

**Estimated Time:** 1.5 hours

---

## Phase 4: OCR Detection & Parsing

**Goal:** Reliably read student ID text from ID cards using OCR

### Task 4.1: Implement Basic OCR Detection

- [x] Write function to detect ID text in image (using pytesseract)
- [x] Extract bounding box coordinates (x, y, width, height)
- [ ] Return confidence score if available
- [ ] Handle case where no ID text is found

**Success Criteria:** Detects ID text region in 90%+ of test images

**Estimated Time:** 2 hours

---

### Task 4.2: Implement OCR Parsing

- [ ] Write function to parse OCR text from image
- [ ] Extract student ID string
- [ ] Validate student ID format
- [ ] Validate decoded data format
- [ ] Handle decoding failures gracefully

**Success Criteria:** Extracts student ID correctly from clear images

**Estimated Time:** 1.5 hours

---

### Task 4.3: Combine Detection + Decoding

- [ ] Write combined function: `scan_card(image)`
- [ ] Integrate preprocessing pipeline before detection
- [ ] Return structured result: `{student_id, bbox, confidence}`
- [ ] Add retry logic with different preprocessing (if first attempt fails)
- [ ] Log all scan attempts and results

**Success Criteria:** Single function call reliably returns OCR data

**Estimated Time:** 2 hours

---

### Task 4.4: Handle Edge Cases

- [ ] Handle multiple text regions in single image
- [ ] Handle partially visible text
- [ ] Handle damaged/worn text
- [ ] Add minimum confidence threshold
- [ ] Implement maximum retry attempts (3 retries)

**Success Criteria:** System handles edge cases without crashing

**Estimated Time:** 2 hours

---

### Task 4.5: Test OCR Reader

- [ ] Create `tests/test_ocr_reader.py`
- [ ] Test detection with clear images
- [ ] Test detection with poor lighting
- [ ] Test detection with angled cards
- [ ] Test decoding accuracy
- [ ] Test edge case handling
- [ ] Run all tests and fix bugs

**Success Criteria:** 95%+ detection rate on test dataset

**Estimated Time:** 2 hours

---

## Phase 5: Error Handling & Robustness

**Goal:** Make system resilient to failures

### Task 5.1: Define Custom Exceptions

- [ ] Create `exceptions.py` file
- [ ] Define `OCRNotFoundError` exception
- [ ] Define `MultipleTextRegionError` exception
- [ ] Define `OCRDecodeError` exception
- [ ] Define `CameraError` exception
- [ ] Add descriptive error messages for each

**Success Criteria:** All custom exceptions defined and importable

**Estimated Time:** 30 minutes

---

### Task 5.2: Integrate Exception Handling

- [ ] Raise appropriate exceptions on OCR failures
- [ ] Update `image_capture.py` to raise `CameraError` on failures
- [ ] Add try-except blocks around all CV operations
- [ ] Log exceptions with full context (timestamp, image path, error details)
- [ ] Test that exceptions propagate correctly to caller

**Success Criteria:** System provides clear error messages for all failure modes

**Estimated Time:** 2 hours

---

### Task 5.3: Implement Retry Logic

- [ ] Create retry wrapper function (max 3 attempts)
- [ ] Add progressive backoff (wait 0.5s between retries)
- [ ] Try different preprocessing on each retry
- [ ] Log each retry attempt
- [ ] Return detailed failure report after exhausting retries

**Success Criteria:** System automatically recovers from temporary failures

**Estimated Time:** 1.5 hours

---

## Phase 6: System Integration & Testing

**Goal:** Integrate CV module with main system

### Task 6.1: Create Public API

- [ ] Update `computer_vision/__init__.py`
- [ ] Export main functions: `scan_card()`, `verify_card()`
- [ ] Create simple usage examples
- [ ] Document expected input/output formats
- [ ] Version the API (v1.0)

**Success Criteria:** High-level controller can import and use CV functions easily

**Estimated Time:** 1 hour

---

### Task 6.2: Integration with Database

- [ ] Define data structure for card mapping: `{slot_index: student_id}`
- [ ] Write function to scan card and return mapping data
- [ ] Write function to verify card matches expected student ID
- [ ] Add database logging for all scan operations
- [ ] Test database writes and reads

**Success Criteria:** CV scan results successfully stored in database

**Estimated Time:** 2 hours

---

### Task 6.3: Create End-to-End Test

- [ ] Simulate staff card loading workflow
- [ ] Scan 10 cards, store mappings
- [ ] Simulate student retrieval workflow
- [ ] Verify each card against expected student ID
- [ ] Measure total time for complete workflow
- [ ] Document any failures or issues

**Success Criteria:** Complete workflow executes without manual intervention

**Estimated Time:** 2 hours

---

### Task 6.4: Performance Benchmarking

- [ ] Measure average scan time (target: <500ms)
- [ ] Measure detection success rate (target: >95%)
- [ ] Measure false positive rate (target: <2%)
- [ ] Test under different lighting conditions
- [ ] Test with 50+ different OCR images
- [ ] Document results in `docs/performance_benchmarks.md`

**Success Criteria:** System meets or exceeds performance targets

**Estimated Time:** 3 hours

---

## Phase 7: Camera Calibration & Optimization

**Goal:** Maximize accuracy and speed

### Task 7.1: Camera Calibration

- [ ] Print checkerboard calibration pattern (9x6 or similar)
- [ ] Capture 20+ images of checkerboard at different angles
- [ ] Save images to `data/calibration_images/`
- [ ] Run OpenCV calibration algorithm
- [ ] Extract intrinsic matrix and distortion coefficients
- [ ] Save calibration data to `config/calibration_data.json`

**Success Criteria:** Camera calibration completes, distortion correction works

**Estimated Time:** 3 hours

---

### Task 7.2: Apply Calibration to Pipeline

- [ ] Load calibration data on system startup
- [ ] Apply lens distortion correction to captured images
- [ ] Compare OCR detection before/after correction
- [ ] Measure performance improvement
- [ ] Make calibration optional (config flag)

**Success Criteria:** Calibrated system detects text more reliably at angles

**Estimated Time:** 2 hours

---

### Task 7.3: Optimize Processing Speed

- [ ] Profile code to find bottlenecks (use cProfile)
- [ ] Reduce image resolution if possible (test 640x480)
- [ ] Process only region of interest (crop before processing)
- [ ] Cache preprocessed images if multiple operations needed
- [ ] Optimize preprocessing pipeline order
- [ ] Measure speed improvement

**Success Criteria:** Processing time reduced by 30%+ without accuracy loss

**Estimated Time:** 3 hours

---

## Phase 8: Documentation & Deployment Prep

**Goal:** Prepare system for deployment and handover

### Task 8.1: Write Setup Guide

- [ ] Create `docs/cv_setup_guide.md`
- [ ] Document camera installation procedure
- [ ] Document lighting setup requirements
- [ ] Document calibration procedure
- [ ] Include troubleshooting section
- [ ] Add photos/diagrams of proper setup

**Success Criteria:** Someone unfamiliar with the project can set up CV system using guide

**Estimated Time:** 3 hours

---

### Task 8.2: Create API Reference

- [ ] Document all public functions in `__init__.py`
- [ ] Include function signatures, parameters, return values
- [ ] Add usage examples for each function
- [ ] Document all custom exceptions
- [ ] Explain configuration options
- [ ] Save as `docs/cv_api_reference.md`

**Success Criteria:** Complete API documentation available

**Estimated Time:** 2 hours

---

### Task 8.3: Final System Validation

- [ ] Run all unit tests, ensure 100% pass
- [ ] Run integration tests with real hardware
- [ ] Test with 100+ OCR scans
- [ ] Verify error handling works correctly
- [ ] Test recovery from camera disconnection
- [ ] Document any known limitations

**Success Criteria:** System validated and ready for deployment

**Estimated Time:** 3 hours

---

### Task 8.4: Code Cleanup & Review

- [ ] Remove debug print statements
- [ ] Remove unused imports
- [ ] Add docstrings to all functions
- [ ] Format code with Black or autopep8
- [ ] Run linter (pylint) and fix issues
- [ ] Update `requirements.txt` with exact versions

**Success Criteria:** Code is clean, documented, and follows Python best practices

**Estimated Time:** 2 hours

---

## Phase 9: Optional Enhancements

**Goal:** Additional features if time permits

### Task 9.1: Add Logging Dashboard (Optional)

- [ ] Create simple visualization of scan success/failure rates
- [ ] Display average processing time
- [ ] Show most common failure modes
- [ ] Generate daily/weekly reports

**Estimated Time:** 4 hours

---

### Task 9.2: Implement Card Quality Check (Optional)

- [ ] Detect if card is damaged or defaced
- [ ] Check if text area is obscured
- [ ] Warn staff about low-quality cards during mapping
- [ ] Log quality metrics

**Estimated Time:** 3 hours

---

### Task 9.3: Add Multi-Threading (Optional)

- [ ] Separate camera capture and image processing into different threads
- [ ] Implement frame buffer for continuous capture
- [ ] Reduce latency between trigger and result
- [ ] Test thread safety

**Estimated Time:** 4 hours

---

## Completion Checklist

**Minimum Viable Product (MVP):**

- [ ] All Phase 1-6 tasks completed
- [ ] System scans text reliably (>90% success rate)
- [ ] Error handling works correctly
- [ ] Integration with database functional
- [ ] Basic documentation complete

**Full Production System:**

- [ ] All Phase 1-8 tasks completed
- [ ] Camera calibrated and optimized
- [ ] Comprehensive documentation available
- [ ] System validated with real hardware
- [ ] Performance meets all targets

**Enhanced System (If Time Allows):**

- [ ] Phase 9 optional tasks completed
- [ ] Additional features implemented
- [ ] Advanced error recovery mechanisms

---

## Progress Tracking

**Week 1:** Phases 1-2 (Setup + Basic Capture)  
**Week 2:** Phases 3-4 (Preprocessing + OCR Reading)  
**Week 3:** Phases 5-6 (Error Handling + Integration)  
**Week 4:** Phases 7-8 (Calibration + Documentation)

---

## Notes

- Each task should be marked complete only when success criteria are met
- If stuck on a task for >4 hours, document the blocker and seek help
- Test frequently - don't wait until end to discover issues
- Prioritize reliability over speed initially
- Document decisions and trade-offs as you go

---

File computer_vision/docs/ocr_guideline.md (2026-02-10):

# OCR Implementation Guideline for ID Card System

## Project: Self-Service Student ID Card Issuance - OCR Module

**Purpose:** Step-by-step guide for implementing an OCR-based student ID extraction system to replace the previous detection approach.

**Estimated Total Time:** 2-3 weeks (working part-time)

---

## Overview of OCR Approach

Instead of relying on legacy scanning, we will use **Optical Character Recognition (OCR)** to directly read the student ID number printed on the card. This approach is more robust and doesn't depend on printing quality.

### Pipeline Architecture

Raw Image → Card Detection → Perspective Correction → ROI Extraction → OCR → Student ID

**Key Advantages:**

- No dependency on special symbology quality; OCR uses printed text directly
- More robust to card orientation and lighting
- Can extract additional information (name, program, etc.)
- Provides fallback if one text region is damaged

---

## Phase 1: Environment Setup & Testing

### Task 1.1: Install OCR Dependencies

**Goal:** Set up Tesseract OCR engine and Python bindings

**Steps:**

- [x] Update system packages
- [x] Install Tesseract OCR engine
- [x] Verify Tesseract installation
- [x] Install Python OCR library
- [x] Test pytesseract import

**Success Criteria:** Tesseract and pytesseract are installed and importable

**Estimated Time:** 30 minutes

---

### Task 1.2: Prepare Test Card Images

**Goal:** Create a diverse dataset for testing OCR accuracy

**Steps:**

- [x] Collect 10-15 sample ID cards (with permission)
- [x] Photograph cards at different conditions:
  - Various distances: 20cm, 30cm, 40cm
  - Various angles: 0°, 15°, 30°, 45°
  - Different lighting: bright, dim, natural light, artificial light
  - Different orientations: portrait, landscape, slightly rotated
- [x] Save images to `data/test_cards/`
- [x] Document card layout:
  - Where is the student ID located? (top, middle, bottom)
  - What format? (e.g., "2020-04-12345" or "2020/04/12345")
  - What font is used?
  - Are there any special characters or patterns?

**Success Criteria:** At least 30 test images with varied conditions

**Estimated Time:** 2 hours

---

### Task 1.3: Understand Your Card Layout

**Goal:** Document the exact structure of your university's ID cards

**Steps:**

- [x] Create a reference document (`docs/card_layout.md`) with:
  - Physical dimensions of the card
  - Location of student ID text (measure from top-left corner)
  - Student ID format (exact regex pattern)
  - Location of other useful text (name, program, year)
  - Font characteristics
  - Background color/pattern in text regions
- [x] Take a high-quality scan of one card
- [x] Mark ROI coordinates on the image using an image editor
- [x] Document typical variations (older cards vs newer cards)

**Success Criteria:** Clear documentation of card layout with measurements

**Estimated Time:** 1 hour

---

## Phase 2: Card Detection

### Task 2.1: Implement Basic Card Detection

**Goal:** Detect the physical card in the image and extract its boundary

**File to create:** `computer_vision/core/card_detector.py`

**Steps:**

- [x] Create the file with basic structure
- [x] Implement preprocessing:
  - Convert to grayscale
  - Apply Gaussian blur (kernel size 5x5)
  - Apply Canny edge detection (thresholds: 50, 150)
- [x] Implement contour detection:
  - Find all contours using `cv2.findContours()`
  - Sort contours by area (largest first)
  - Filter contours by:
    - Minimum area (e.g., 10,000 pixels)
    - Number of sides (should be 4 for rectangular card)
    - Aspect ratio (ID cards are typically 1.586:1, CR80 standard)
- [x] Implement corner detection:
  - Use `cv2.approxPolyDP()` to get 4 corner points
  - Return corners in order: top-left, top-right, bottom-right, bottom-left
- [x] Add error handling for:
  - No card found
  - Multiple cards detected
  - Invalid card shape

**Function signature:**

**Success Criteria:**

- Detects card in 90%+ of test images
- Returns correct 4 corner points
- Handles edge cases gracefully

**Estimated Time:** 3 hours

---

### Task 2.2: Test Card Detection

**Goal:** Validate card detection works reliably

**File to create:** `computer_vision/tests/manual_tests/test_card_detection.py`

**Steps:**

- [x] Create test script that:
  - Loads test images from `data/test_cards/`
  - Runs card detection on each
  - Draws detected corners on the image
  - Saves annotated images to `data/detection_results/`
  - Prints success/failure statistics
- [x] Run tests on all images
- [x] Analyze failures:
  - Document which lighting conditions fail
  - Document which angles fail
  - Note any patterns
- [x] Adjust detection parameters based on results:
  - Canny thresholds
  - Minimum area
  - Aspect ratio tolerance
- [x] Re-test until 90%+ success rate

**Success Criteria:** 90%+ detection rate on test dataset

**Estimated Time:** 2 hours

---

## Phase 3: Perspective Correction

### Task 3.1: Implement Perspective Transform

**Goal:** Convert detected card to a top-down, straightened view

**File to create:** `computer_vision/core/perspective_corrector.py`

**Steps:**

- [x] Create helper function to order corner points consistently

- [x] Implement perspective transformation:
  - Calculate output dimensions based on corner distances
  - Create destination rectangle coordinates
  - Compute perspective transformation matrix using `cv2.getPerspectiveTransform()`
  - Apply transformation using `cv2.warpPerspective()`
- [x] Handle aspect ratio preservation:
  - Ensure output matches standard ID card ratio (85.60mm × 53.98mm = 1.586:1)
  - Resize to standard resolution (e.g., 856 × 539 pixels)
- [x] Add quality checks:
  - Verify output is not too distorted
  - Check for black borders (indicate bad transformation)

**Function signature:**

**Success Criteria:**

- Produces straight, rectangular card images
- Maintains text readability
- Consistent output size

**Estimated Time:** 2 hours

---

### Task 3.2: Test Perspective Correction

**Goal:** Verify perspective correction works correctly

**File to create:** `computer_vision/tests/manual_tests/test_perspective.py`

**Steps:**

- [x] Create test script that:
  - Detects card
  - Applies perspective correction
  - Saves straightened card images
- [x] Visual inspection of results:
  - Text should be horizontal and readable
  - No excessive distortion
  - Aspect ratio looks correct
- [x] Measure output dimensions
- [x] Test with extreme angles (30°, 45°)

**Success Criteria:** Straightened cards are readable and properly oriented

**Estimated Time:** 1 hour

---

## Phase 4: ROI Extraction

### Task 4.1: Define ROI Regions

**Goal:** Extract specific regions containing student ID and other text

**File to create:** `computer_vision/core/roi_extractor.py`

**Steps:**

- [x] Based on your card layout documentation, define ROI coordinates
  - Student ID region (primary)
  - Name region (optional, for validation)
  - Program/year region (optional)
- [x] Implement ROI extraction function using array slicing
- [x] Add configuration file for ROI parameters:
  - Create `config/ocr_config.py`
  - Define ROI as ratios of card dimensions:

- [x] Make ROI extraction configurable for different card layouts

**Function signature:**

**Success Criteria:**

- Extracted ROIs contain the target text
- Minimal background/noise in ROIs
- Works across different card orientations

**Estimated Time:** 2 hours

---

### Task 4.2: Test ROI Extraction

**Goal:** Verify ROI coordinates are correct

**File to create:** `computer_vision/tests/manual_tests/test_roi_extraction.py`

**Steps:**

- [x] Create test script that:
  - Processes cards through detection → straightening → ROI extraction
  - Saves each ROI as separate image
  - Annotates original card with ROI boundaries
- [x] Visual verification:
  - Check that student ID is fully visible in extracted ROI
  - Verify no important text is cut off
  - Ensure minimal background noise
- [x] Test with 10+ different cards
- [x] Adjust ROI coordinates if needed
- [x] Document final ROI parameters

**Success Criteria:** Student ID is centered and complete in extracted ROI

**Estimated Time:** 1.5 hours

---

## Phase 5: Image Preprocessing for OCR

### Task 5.1: Implement OCR-Specific Preprocessing

**Goal:** Enhance ROI images to maximize OCR accuracy

**File to update:** `computer_vision/core/image_utils.py`

**Steps:**

- [x] Add preprocessing functions (contrast, denoise, binarize):

  **Contrast Enhancement:**

  **Denoising:**

  **Binarization:**

  **Deskewing (if text is slightly tilted):**

- [x] Create preprocessing pipeline:
- [x] Make pipeline configurable (enable/disable specific steps)

**Success Criteria:**

- Preprocessed images have clear, high-contrast text
- Background noise is minimized
- Text edges are sharp

**Estimated Time:** 3 hours

---

### Task 5.2: Test Preprocessing Quality

**Goal:** Compare OCR results with and without preprocessing

**File to create:** `computer_vision/tests/manual_tests/test_preprocessing.py`

**Steps:**

- [x] Create test script that shows before/after:
  - Original ROI
  - After each preprocessing step
  - Final preprocessed image
- [x] Save comparison images
- [x] Visual inspection of text clarity
- [x] Try different preprocessing combinations
- [x] Benchmark which combination works best:
  - Test on 5 sample cards
  - Try different orders of operations
  - Document best pipeline

**Success Criteria:** Clear improvement in text visibility

**Estimated Time:** 2 hours

---

## Phase 6: OCR Implementation

### Task 6.1: Implement Basic OCR

**Goal:** Extract text from preprocessed ROI

**File to update:** Use pytesseract directly in the OCR step

**Steps:**

- [x] Import pytesseract
- [x] Implement basic OCR function:
- [x] Configure Tesseract for ID cards:
  - Page segmentation mode (PSM): Try PSM 6 (uniform block) or PSM 7 (single line)
  - OCR Engine Mode (OEM): Use OEM 3 (default)
  - Whitelist characters (only allow digits, letters, hyphens):
- [x] Test different Tesseract configurations:
  - PSM 3, 6, 7, 11
  - Different whitelists
  - Different OEM modes
  - Document which works best

**Success Criteria:**

- Can extract text from clear ROI images
- Minimal garbage characters in output

**Estimated Time:** 2 hours

---

### Task 6.2: Implement Student ID Extraction

**Goal:** Parse raw OCR text to extract valid student ID

**Steps:**

- [x] Define student ID pattern (regex):
  - Based on your card format documentation
  - Example: `r'\\d{4}-\\d{2}-\\d{5}'` for format "2020-04-12345"
  - Or: `r'\\d{4}/\\d{2}/\\d{5}'` for format "2020/04/12345"
  - Make it configurable in `config/ocr_config.py`
- [x] Implement extraction function:
- [x] Add validation checks:
  - Length validation
  - Year range validation (e.g., 2015-2030)
  - Checksum validation (if your IDs have checksums)

- [x] Handle common OCR errors:
  - "O" vs "0" (letter O vs zero)
  - "I" vs "1" (letter I vs one)
  - "S" vs "5"
  - Implement character correction logic

**Success Criteria:**

- Correctly extracts student ID from clear images
- Filters out invalid patterns
- Robust to common OCR mistakes

**Estimated Time:** 3 hours

---

### Task 6.3: Implement Retry Logic

**Goal:** Improve accuracy through multiple extraction attempts

**Steps:**

- [x] Implement retry mechanism with different strategies:

  **Strategy 1:** Original preprocessing
  **Strategy 2:** Higher contrast
  **Strategy 3:** Different binarization threshold
  **Strategy 4:** Different Tesseract PSM mode
  **Strategy 5:** Inverted image (white text on black background)

- [x] Implement voting system:
  - Run 3-5 extraction attempts with different strategies
  - If multiple attempts return the same ID, use that (high confidence)
  - If all differ, return most common or flag for manual review

- [x] Add confidence scoring:
  - Based on Tesseract confidence scores
  - Based on regex match strength
  - Based on voting consensus

**Success Criteria:**

- Increased accuracy through retries
- Clear confidence metrics

**Estimated Time:** 3 hours

---

## Phase 7: Integration & Testing

### Task 7.1: Create Complete OCR Pipeline

**Goal:** Integrate all components into single pipeline

**File to create:** `computer_vision/pipeline/ocr_pipeline.py`

**Steps:**

- [x] Create pipeline class:
- [x] Implement full pipeline flow:
  1. Detect card (raise CardNotFoundError if failed)
  2. Apply perspective correction
  3. Extract ROI
  4. Preprocess ROI
  5. Extract student ID with retries
  6. Return structured result

- [x] Add comprehensive logging:
  - Log each pipeline stage
  - Log processing times
  - Log confidence scores
  - Save debug images (optional)

- [x] Add timing measurements:
  - Measure total processing time
  - Measure per-stage time
  - Optimize if > 1 second

**Success Criteria:**

- Single function call processes complete workflow
- Returns structured, predictable output
- Handles all error cases gracefully

**Estimated Time:** 3 hours

---

### Task 7.2: Create Test Suite

**Goal:** Comprehensive testing of OCR pipeline

**File to create:** `computer_vision/tests/test_ocr_pipeline.py`

**Steps:**

- [x] Create automated test script:
  - Test directory of images
  - Expected results file (JSON mapping image → student_id)
  - Run pipeline on each image
  - Compare actual vs expected
  - Calculate accuracy metrics

- [x] Test metrics to measure:
  - **Detection Rate:** % of images where card was detected
  - **Extraction Rate:** % of detected cards where ID was extracted
  - **Accuracy Rate:** % of extracted IDs that match expected
  - **Overall Success Rate:** End-to-end success
  - **Average Processing Time:** Mean time per card
  - **Confidence Distribution:** Histogram of confidence scores
- [ ] Create test report template:

**Success Criteria:**

- Test suite runs automatically
- Generates detailed report
- Identifies failure patterns

**Estimated Time:** 3 hours

---

### Task 7.3: Benchmark and Optimize

**Goal:** Meet performance targets

**Target Metrics:**

- Detection rate: **> 95%**
- Extraction accuracy: **> 90%**
- Processing time: **< 1 second per card**

**Steps:**

- [ ] Run comprehensive test on 50+ cards
- [ ] Analyze results:
  - Which cards fail? Why?
  - Which preprocessing works best?
  - Which Tesseract config is optimal?
- [ ] Optimization strategies:
  - **If detection failing:**
    - Adjust Canny thresholds
    - Adjust area/aspect ratio filters
    - Add morphological operations
  - **If OCR failing:**
    - Try different preprocessing
    - Adjust binarization thresholds
    - Try different Tesseract PSM modes
    - Expand character whitelist
  - **If too slow:**
    - Reduce image resolution
    - Process only necessary ROI
    - Skip unnecessary preprocessing steps
    - Cache preprocessing results
- [ ] Iterate until targets are met
- [ ] Document final configuration

**Success Criteria:** Meet all performance targets

**Estimated Time:** 4 hours

---

## Phase 8: Error Handling & Robustness

### Task 8.1: Implement Comprehensive Error Handling

**Goal:** Handle all failure modes gracefully

**Steps:**

- [x] Update `computer_vision/core/exceptions.py` with:
  - `CardNotFoundError`: No card in image
  - `CardDetectionAmbiguousError`: Multiple cards detected
  - `PerspectiveCorrectionError`: Invalid transformation
  - `OCRExtractionError`: Failed to extract student ID
  - `InvalidStudentIDError`: Extracted ID fails validation

- [x] Add error handling to each module:
  - Wrap OpenCV operations in try-except
  - Validate inputs (None checks, type checks)
  - Validate outputs (reasonable dimensions, non-empty results)

- [x] Create error recovery strategies:
  - If card detection fails: suggest better positioning
  - If OCR fails on first attempt: try alternative preprocessing
  - If extracted ID is invalid: flag for manual review

**Success Criteria:**

- System never crashes on bad input
- Clear error messages for all failure modes
- Logging provides debugging information

**Estimated Time:** 2 hours

---

### Task 8.2: Test Edge Cases

**Goal:** Ensure robustness to unusual inputs

**Test Cases:**

- [ ] No card in image
- [ ] Multiple cards in image
- [ ] Card partially outside frame
- [ ] Extremely poor lighting (very dark/bright)
- [ ] Blurry images
- [ ] Damaged/worn cards
- [ ] Cards with stickers or annotations
- [ ] Empty image / None input
- [ ] Wrong image format (not BGR)
- [ ] Very small images (< 100x100)
- [ ] Rotated 90°, 180°, 270°

**Success Criteria:** All edge cases handled without crashes

**Estimated Time:** 2 hours

---

## Phase 9: Integration with Main System

### Task 9.1: Create Public API

**Goal:** Simple interface for main system to use OCR module

**File to update:** `computer_vision/__init__.py`

**Steps:**

- [ ] Export main pipeline:
- [ ] Create usage examples in `examples/basic_usage.py`
- [ ] Document API in `docs/ocr_api_reference.md`

**Success Criteria:** Main system can use OCR with single function call

**Estimated Time:** 2 hours

---

### Task 9.2: Database Integration

**Goal:** Store OCR results and maintain card-to-slot mapping

**Steps:**

- [ ] Define database schema for card mapping:
- [ ] Create functions to:
  - Store scan result: `store_card_scan(student_id, slot_index, confidence)`
  - Verify card match: `verify_card(expected_id, scanned_id) -> bool`
  - Update card status: `mark_card_dispensed(student_id)`
- [ ] Add transaction logging:

**Success Criteria:** OCR results persist to database

**Estimated Time:** 2 hours

---

## Phase 10: Documentation & Deployment

### Task 10.1: Write User Documentation

**Goal:** Complete documentation for system operators

**Documents to create:**

**1. Setup Guide** (`docs/ocr_setup_guide.md`)

- [ ] Installation instructions
- [ ] Camera positioning requirements
- [ ] Lighting setup recommendations
- [ ] Configuration file explanations
- [ ] Troubleshooting common issues

**2. API Reference** (`docs/ocr_api_reference.md`)

- [ ] All public functions with signatures
- [ ] Parameter descriptions
- [ ] Return value specifications
- [ ] Usage examples
- [ ] Error handling guide

**3. Maintenance Guide** (`docs/ocr_maintenance.md`)

- [ ] How to update ROI coordinates for new card designs
- [ ] How to retrain for different fonts
- [ ] Performance monitoring
- [ ] Log analysis

**Success Criteria:** Complete, clear documentation

**Estimated Time:** 4 hours

---

### Task 10.2: Create Calibration Tool

**Goal:** Easy way to adjust ROI coordinates for different card layouts

**File to create:** `computer_vision/tools/roi_calibrator.py`

**Steps:**

- [ ] Create interactive tool:
  - Load sample card image
  - Display card
  - Allow user to draw rectangles for ROI regions
  - Export ROI coordinates to config file

- [ ] Add validation:
  - Show extracted ROI preview
  - Test OCR on extracted ROI
  - Verify student ID is detected

**Success Criteria:** Non-technical user can calibrate ROI

**Estimated Time:** 3 hours

---

### Task 10.3: Final System Validation

**Goal:** End-to-end testing with real hardware

**Steps:**

- [ ] Set up camera in kiosk
- [ ] Test with 100+ real cards
- [ ] Measure performance:
  - Detection rate
  - Accuracy rate
  - Processing time
  - Error rate

- [ ] Stress testing:
  - Continuous operation for 1 hour
  - Process 50 cards back-to-back
  - Test under different lighting (morning, afternoon, evening)
  - Test after Raspberry Pi reboot

- [ ] Security testing:
  - Try with photocopies (should fail or warn)
  - Try with printed photos of cards
  - Try with expired cards from different years

- [ ] Document results in `docs/validation_report.md`

**Success Criteria:** System meets all operational requirements

**Estimated Time:** 4 hours

---

## Configuration Reference

### Key Configuration Parameters

**`config/ocr_config.py`**

---

## Performance Targets

| Metric | Target  | Acceptable | Needs Improvement |
| --- | --- | --- | --- |
| Card Detection Rate | > 98% | > 95% | < 95% |
| ID Extraction Accuracy | > 95% | > 90% | < 90% |
| Processing Time | < 800ms | < 1200ms | > 1200ms |
| False Positive Rate | < 1% | < 2% | > 2% |
| System Uptime | > 99% | > 95% | < 95% |

---

## Troubleshooting Guide

### Problem: Card not detected

**Possible causes:**

- Card too far from camera
- Poor lighting (too dark or too bright)
- Card outside camera frame
- Reflective card surface causing glare

**Solutions:**

- Adjust camera position/distance
- Improve lighting setup (diffuse, even lighting)
- Add lighting guidelines in user instructions
- Adjust Canny edge detection thresholds
- Use polarizing filter on camera to reduce glare

---

### Problem: OCR extracts wrong student ID

**Possible causes:**

- Poor image quality (blurry, low resolution)
- Font not well-recognized by Tesseract
- Incorrect ROI coordinates
- Damaged card text

**Solutions:**

- Increase camera resolution
- Improve preprocessing (better binarization)
- Try different Tesseract PSM modes
- Train custom Tesseract model for your specific font
- Recalibrate ROI coordinates
- Implement checksum validation to catch errors

---

### Problem: Processing is too slow (> 1 second)

**Possible causes:**

- High resolution images
- Too many preprocessing steps
- Inefficient contour detection

**Solutions:**

- Reduce input image resolution (resize before processing)
- Process only ROI region for OCR (skip full image)
- Optimize preprocessing pipeline (remove unnecessary steps)
- Use threading (separate detection and OCR)
- Cache preprocessed images if multiple operations needed

---

### Problem: Extracting text from wrong region

**Possible causes:**

- ROI coordinates incorrect
- Card layout changed (new card design)
- Perspective correction failed

**Solutions:**

- Use ROI calibration tool to reconfigure
- Review card layout documentation
- Test perspective correction output
- Add visual debugging (save intermediate images)

---

## Progress Tracking

**Week 1:** Phases 1-2 (Setup, Card Detection)  
**Week 2:** Phases 3-5 (Perspective, ROI, Preprocessing)  
**Week 3:** Phases 6-7 (OCR Implementation, Integration)  
**Week 4:** Phases 8-10 (Error Handling, Testing, Documentation)

---

## Success Checklist

### Minimum Viable Product (MVP)

- [ ] Camera captures images successfully
- [ ] Card detection works (> 90% rate)
- [ ] Perspective correction produces straight cards
- [ ] ROI extraction isolates student ID region
- [ ] OCR extracts student ID (> 85% accuracy)
- [ ] Basic error handling implemented
- [ ] Simple API for main system

### Production-Ready System

- [ ] All MVP requirements met
- [ ] Card detection rate > 95%
- [ ] OCR accuracy > 90%
- [ ] Processing time < 1 second
- [ ] Comprehensive error handling
- [ ] Database integration complete
- [ ] Full documentation written
- [ ] System validated with real hardware
- [ ] Edge cases handled

### Enhanced System (Optional)

- [ ] OCR accuracy > 95%
- [ ] Multi-field extraction (name, program, year)
- [ ] Automatic font detection and adaptation
- [ ] Real-time preview for debugging
- [ ] Admin dashboard with statistics
- [ ] Automatic retraining based on failures

---

## Notes and Best Practices

1. **Test Early, Test Often**
   - Don't wait until the end to test integration
   - Create test images for each development stage
   - Keep a separate set of validation images (don't overtrain on test set)

2. **Document as You Go**
   - Keep notes on what works and what doesn't
   - Record all configuration changes
   - Take screenshots of successful results

3. **Start Simple, Iterate**
   - Get basic OCR working first
   - Add complexity gradually
   - Each addition should improve accuracy measurably

4. **Lighting is Critical**
   - Good lighting can compensate for mediocre algorithms
   - Bad lighting makes even the best algorithms fail
   - Invest time in proper lighting setup

5. **Tesseract Tuning**
   - PSM (Page Segmentation Mode) has huge impact on accuracy
   - Try all PSM modes 3, 6, 7, 11 and compare results
   - Character whitelist is very effective for structured text

6. **ROI Precision Matters**
   - Even 5% miscalibration can significantly hurt accuracy
   - Use the calibration tool
   - Test ROI on multiple card samples

7. **Version Control**
   - Commit after each working phase
   - Tag releases (v1.0-mvp, v2.0-production)
   - Keep old configurations in case you need to rollback

8. **Performance vs. Accuracy Trade-off**
   - More preprocessing usually means better accuracy but slower processing
   - Find the sweet spot for your requirements
   - Consider retry logic only for failed cases

---

## Recommended Development Order

1. ✅ Environment setup (Phase 1)
2. ✅ Card detection (Phase 2)
3. ✅ Perspective correction (Phase 3)
4. ✅ ROI extraction (Phase 4)
5. ✅ Preprocessing (Phase 5)
6. ✅ Basic OCR (Phase 6.1)
7. ✅ Student ID extraction (Phase 6.2)
8. ✅ Complete pipeline (Phase 7.1)
9. ✅ Testing and optimization (Phase 7.2-7.3)
10. ✅ Error handling (Phase 8)
11. ✅ Integration (Phase 9)
12. ✅ Documentation (Phase 10)

---

**Remember:** The goal is a reliable, maintainable system. Prioritize robustness over perfection. Good enough to work 95% of the time is better than perfect 80% of the time.

Good luck with your implementation!

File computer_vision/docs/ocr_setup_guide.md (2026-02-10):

# OCR Setup Guide

## Overview

This guide explains how to install dependencies and set up the OCR module for the ID card system.

## 1. System Requirements

- Linux with Python 3.10+
- OpenCV and Tesseract OCR installed
- Camera or image files for testing

## 2. Install Tesseract

Install Tesseract and the English language pack using your package manager.

## 3. Python Environment

Create/activate your Python environment and install requirements:

- `pytesseract`
- `opencv-python`
- `numpy`

## 4. Configuration

Update [computer_vision/config/ocr_config.py](computer_vision/config/ocr_config.py) if needed:

- Anchor text and ROI offsets
- Student ID regex pattern
- Tesseract config and preprocessing parameters

## 5. Test Images

Add test images to [computer_vision/data/test_cards](computer_vision/data/test_cards).

## 6. Run Manual Tests

- Student ID OCR: [computer_vision/tests/manual_tests/test_student_id_ocr.py](computer_vision/tests/manual_tests/test_student_id_ocr.py)
- Preprocessing preview: [computer_vision/tests/manual_tests/test_preprocessing.py](computer_vision/tests/manual_tests/test_preprocessing.py)

## 7. Troubleshooting

- If no card is detected, adjust lighting and card position.
- If OCR fails, tune preprocessing and PSM settings in config.

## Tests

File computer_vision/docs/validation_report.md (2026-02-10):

# OCR System Validation Report

Date: 2026-02-10

## 1. Environment

- Device:
- Camera model:
- Lighting setup:
- Software version/commit:

## 2. Test Summary

- Total cards tested:
- Detection rate:
- OCR extraction rate:
- Accuracy rate:
- Average processing time (ms):

## 3. Stress Tests

- Continuous operation (1 hour):
- Back-to-back scans (50 cards):
- Reboot test:

## 4. Lighting Conditions

- Morning:
- Afternoon:
- Evening:

## 5. Security Tests

- Photocopy:
- Printed photo:
- Expired cards:

## 6. Failure Analysis

- Common failure modes:
- Suggested mitigations:

## 7. Final Assessment

- Meets operational requirements: yes/no
- Notes:

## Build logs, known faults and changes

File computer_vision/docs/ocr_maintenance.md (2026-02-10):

# OCR Maintenance Guide

## 1. Updating ROI Coordinates

If card design changes, update anchor offsets in [computer_vision/config/ocr_config.py](computer_vision/config/ocr_config.py) and re-test:

- Use [computer_vision/tests/manual_tests/test_anchor_roi_extraction.py](computer_vision/tests/manual_tests/test_anchor_roi_extraction.py) or visual tools.

## 2. Tesseract Tuning

- Keep PSM at the best-performing value (currently 6).
- Adjust `char_whitelist` if format changes.

## 3. Preprocessing Tweaks

- Toggle binarization/contrast/denoise in config.
- Re-run [computer_vision/tests/manual_tests/test_preprocessing.py](computer_vision/tests/manual_tests/test_preprocessing.py) after changes.

## 4. Monitoring Performance

- Run [computer_vision/tests/manual_tests/benchmark_pipeline.py](computer_vision/tests/manual_tests/benchmark_pipeline.py) periodically.
- Investigate failures in [computer_vision/tests/test_ocr_pipeline.py](computer_vision/tests/test_ocr_pipeline.py).

## 5. Logs and Debug Images

- Enable `DEBUG.verbose_logging` for console logs.
- Save intermediate outputs using the manual tests for visual checks.

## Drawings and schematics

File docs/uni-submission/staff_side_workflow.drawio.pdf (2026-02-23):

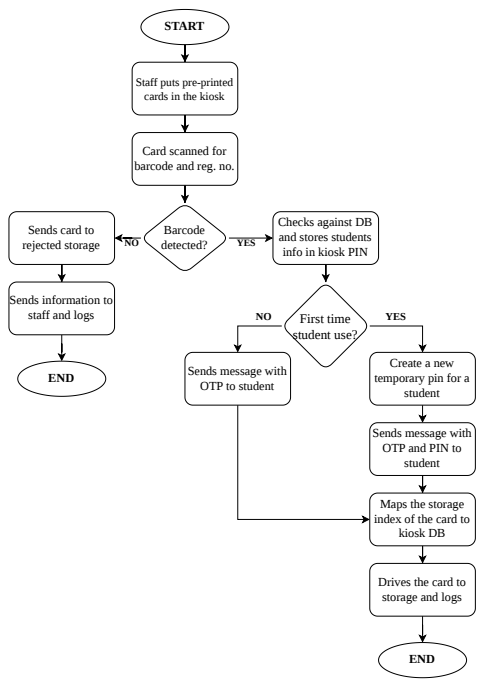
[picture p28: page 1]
START; Barcode detected?; rejected storage; YES; First time student use?; END

Staff puts pre-printed
cards in the kiosk

Card scanned for
barcode and reg. no.

Checks against DB
and stores students
info in kiosk PIN

Sends card to

Sends information to
staff and logs

Sends message with

Create a new
temporary pin for a
student

OTP to student END

OTP and PIN to

Maps the storage
index of the card to
kiosk DB

Drives the card to
storage and logs

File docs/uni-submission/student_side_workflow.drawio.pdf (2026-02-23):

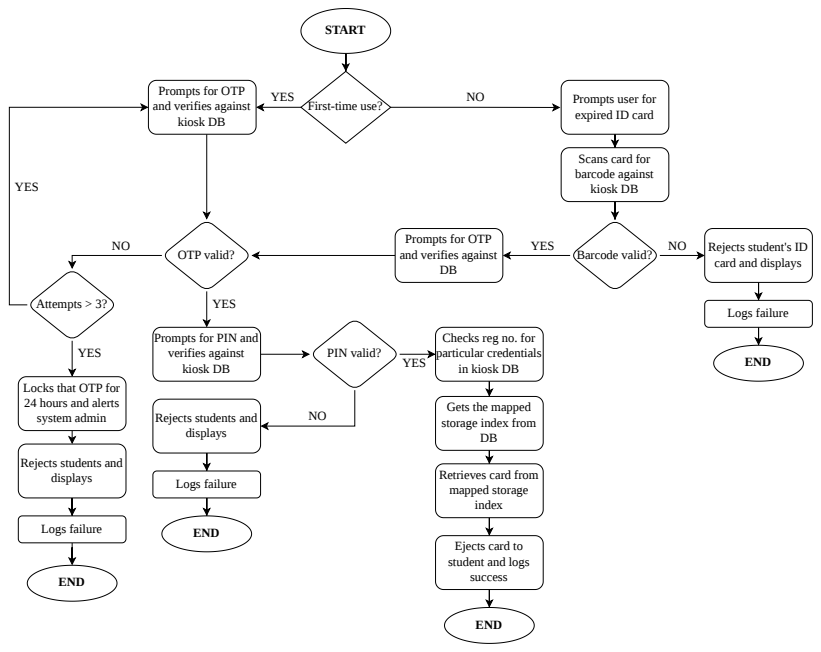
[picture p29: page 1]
START; YES; NO Prompts for OTP; OTP valid?; Logs failure; END; PIN valid?; Attempts > 3?; Barcode valid?; Rejects student's ID

and verifies against
kiosk DB

First-time use?

Prompts user for
expired ID card

Scans card for
barcode against

Prompts for OTP

card and displays

Prompts for PIN and
verifies against

Checks reg no. for
particular credentials
YES

in kiosk DB

Locks that OTP for
24 hours and alerts
system admin

Gets the mapped
storage index from

Rejects students and
displays

Retrieves card from
mapped storage
index

Ejects card to
student and logs
success

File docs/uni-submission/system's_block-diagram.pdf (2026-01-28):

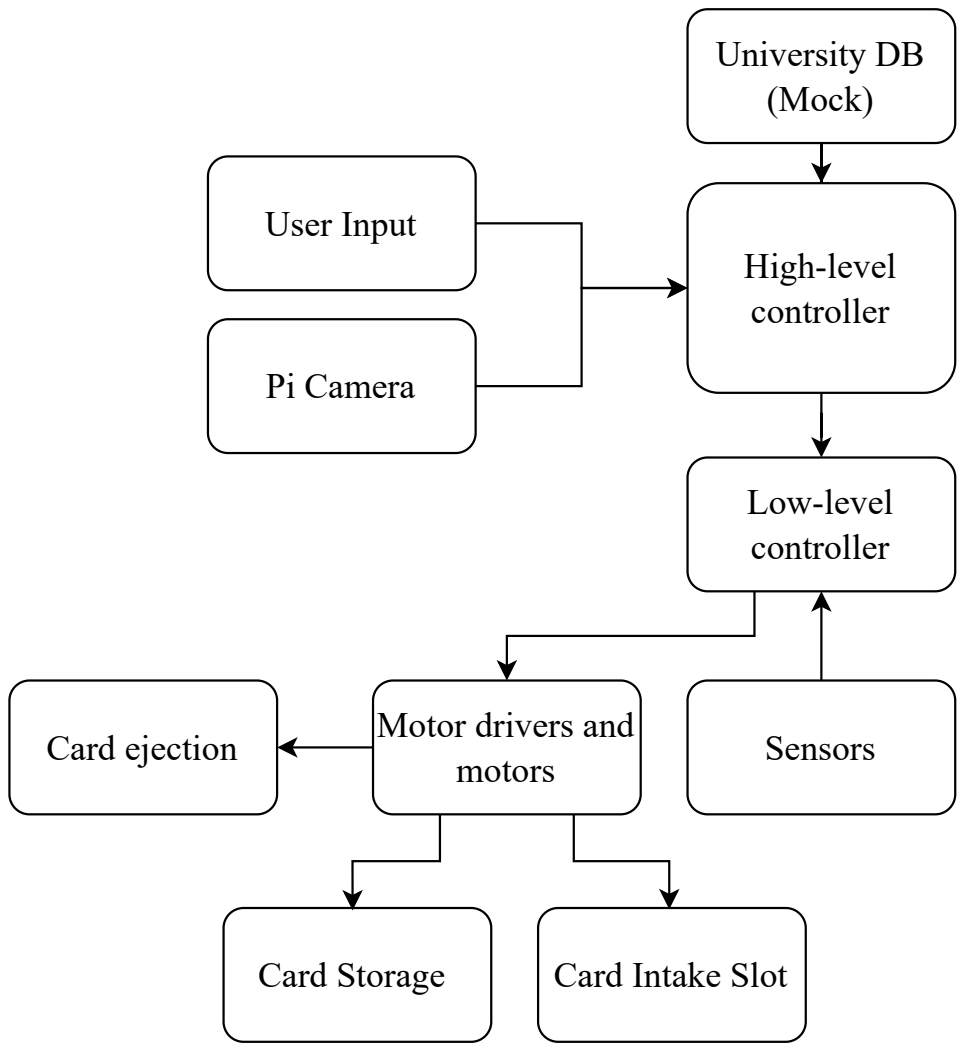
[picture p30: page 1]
University DB (Mock); High-level controller; User Input; Pi Camera; Low-level controller; Card Storage; Card Intake Slot; Card ejection

Sensors Motor drivers and
motors

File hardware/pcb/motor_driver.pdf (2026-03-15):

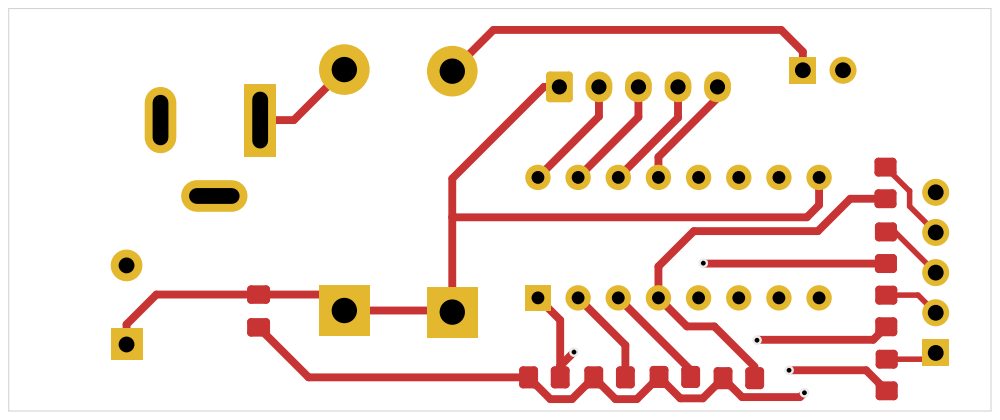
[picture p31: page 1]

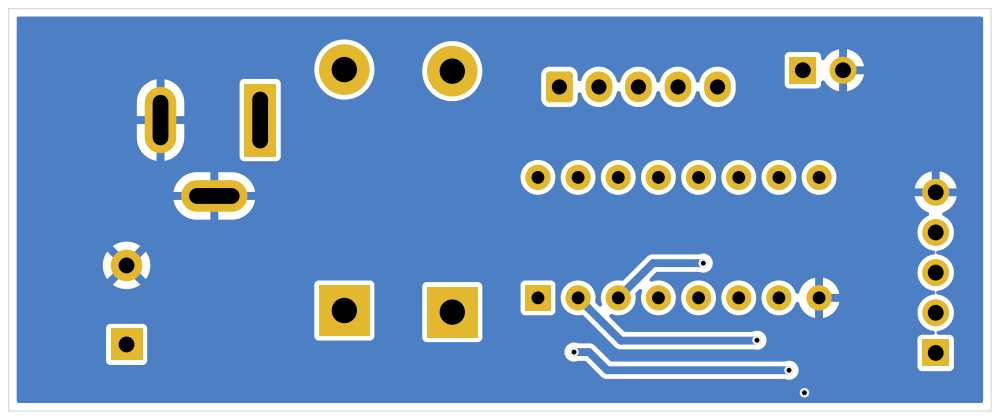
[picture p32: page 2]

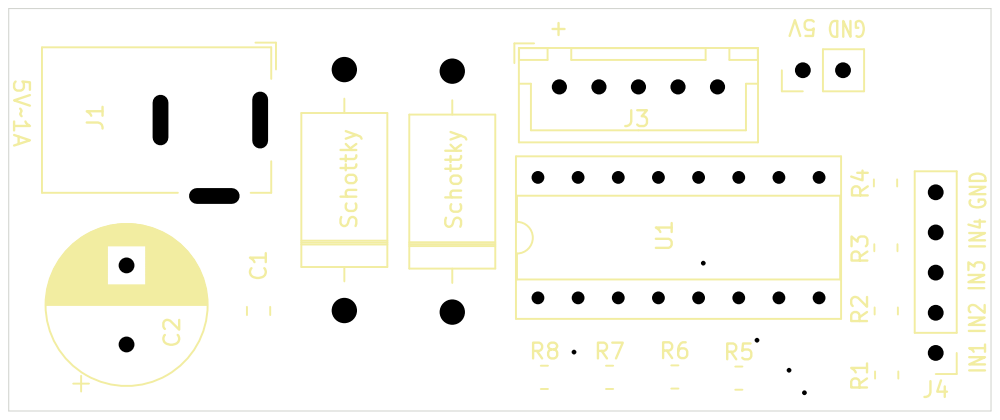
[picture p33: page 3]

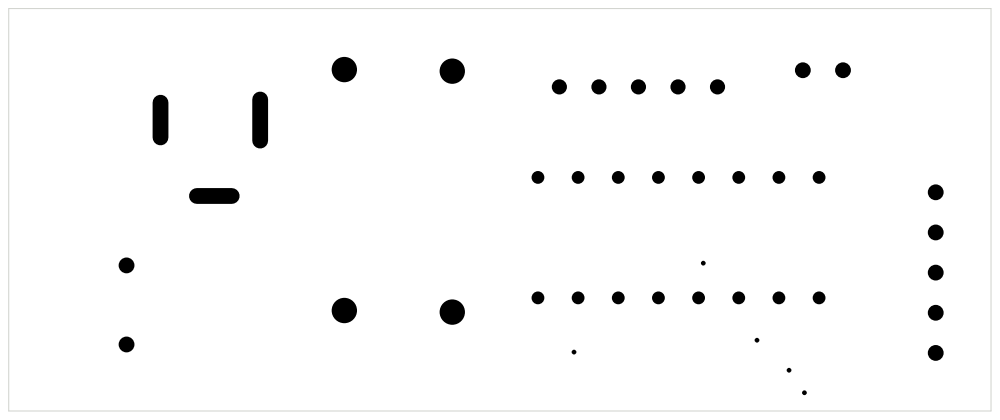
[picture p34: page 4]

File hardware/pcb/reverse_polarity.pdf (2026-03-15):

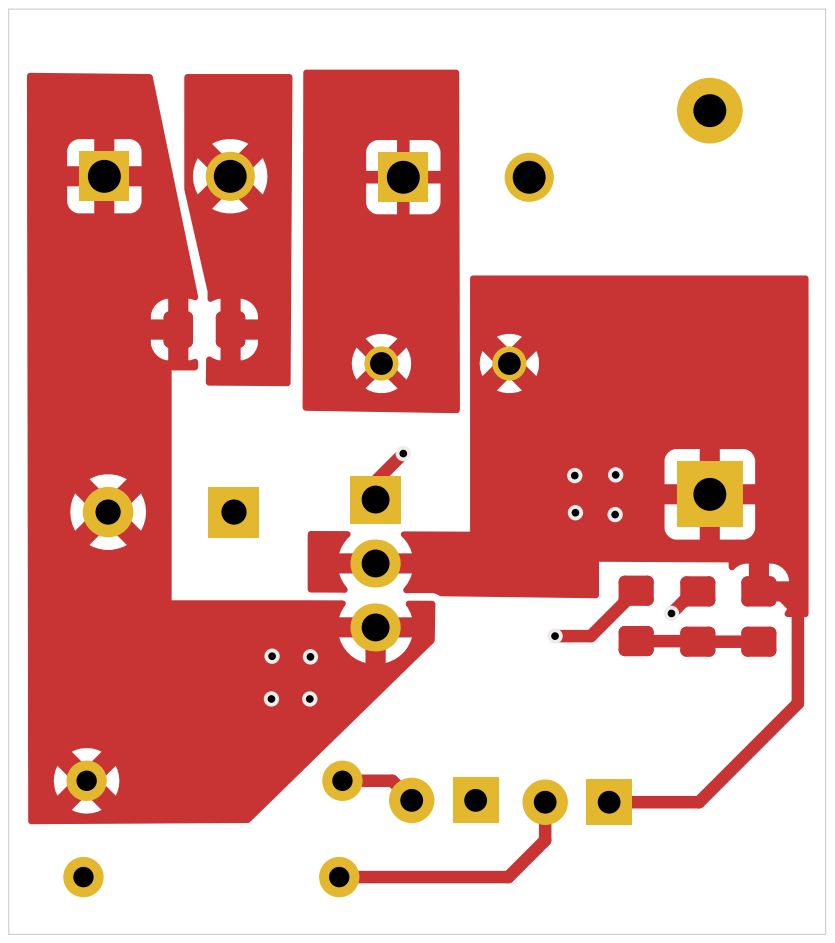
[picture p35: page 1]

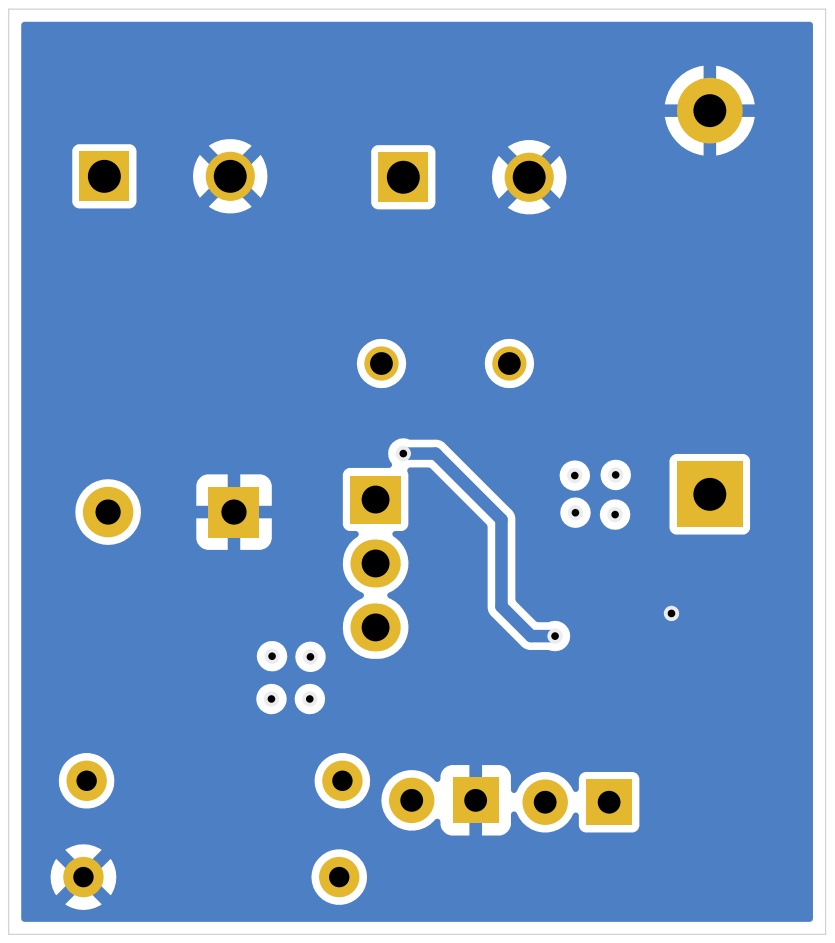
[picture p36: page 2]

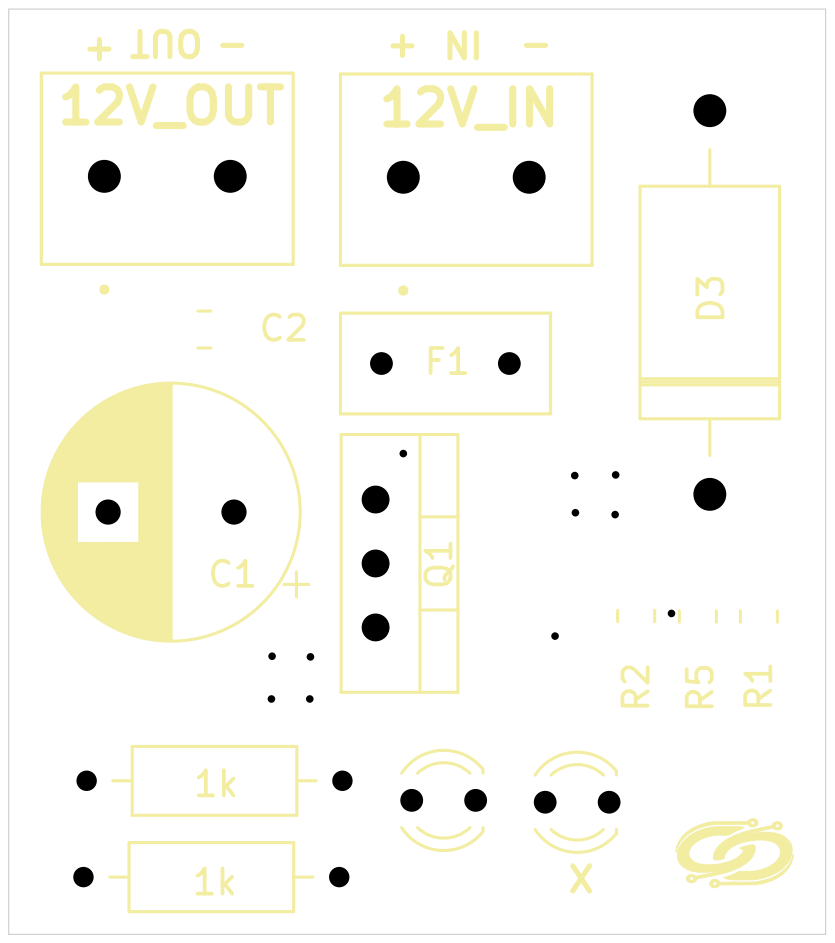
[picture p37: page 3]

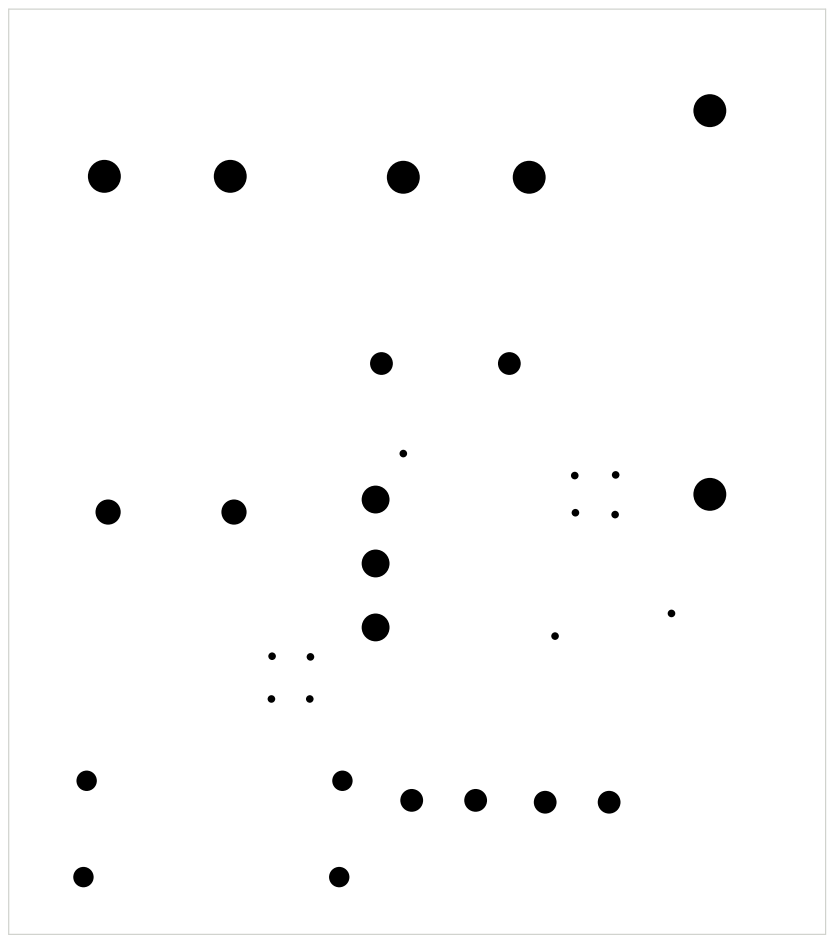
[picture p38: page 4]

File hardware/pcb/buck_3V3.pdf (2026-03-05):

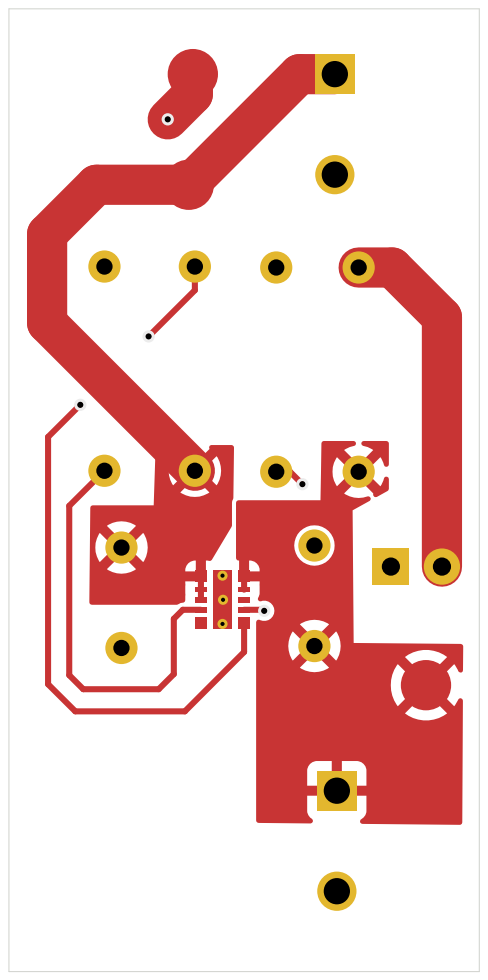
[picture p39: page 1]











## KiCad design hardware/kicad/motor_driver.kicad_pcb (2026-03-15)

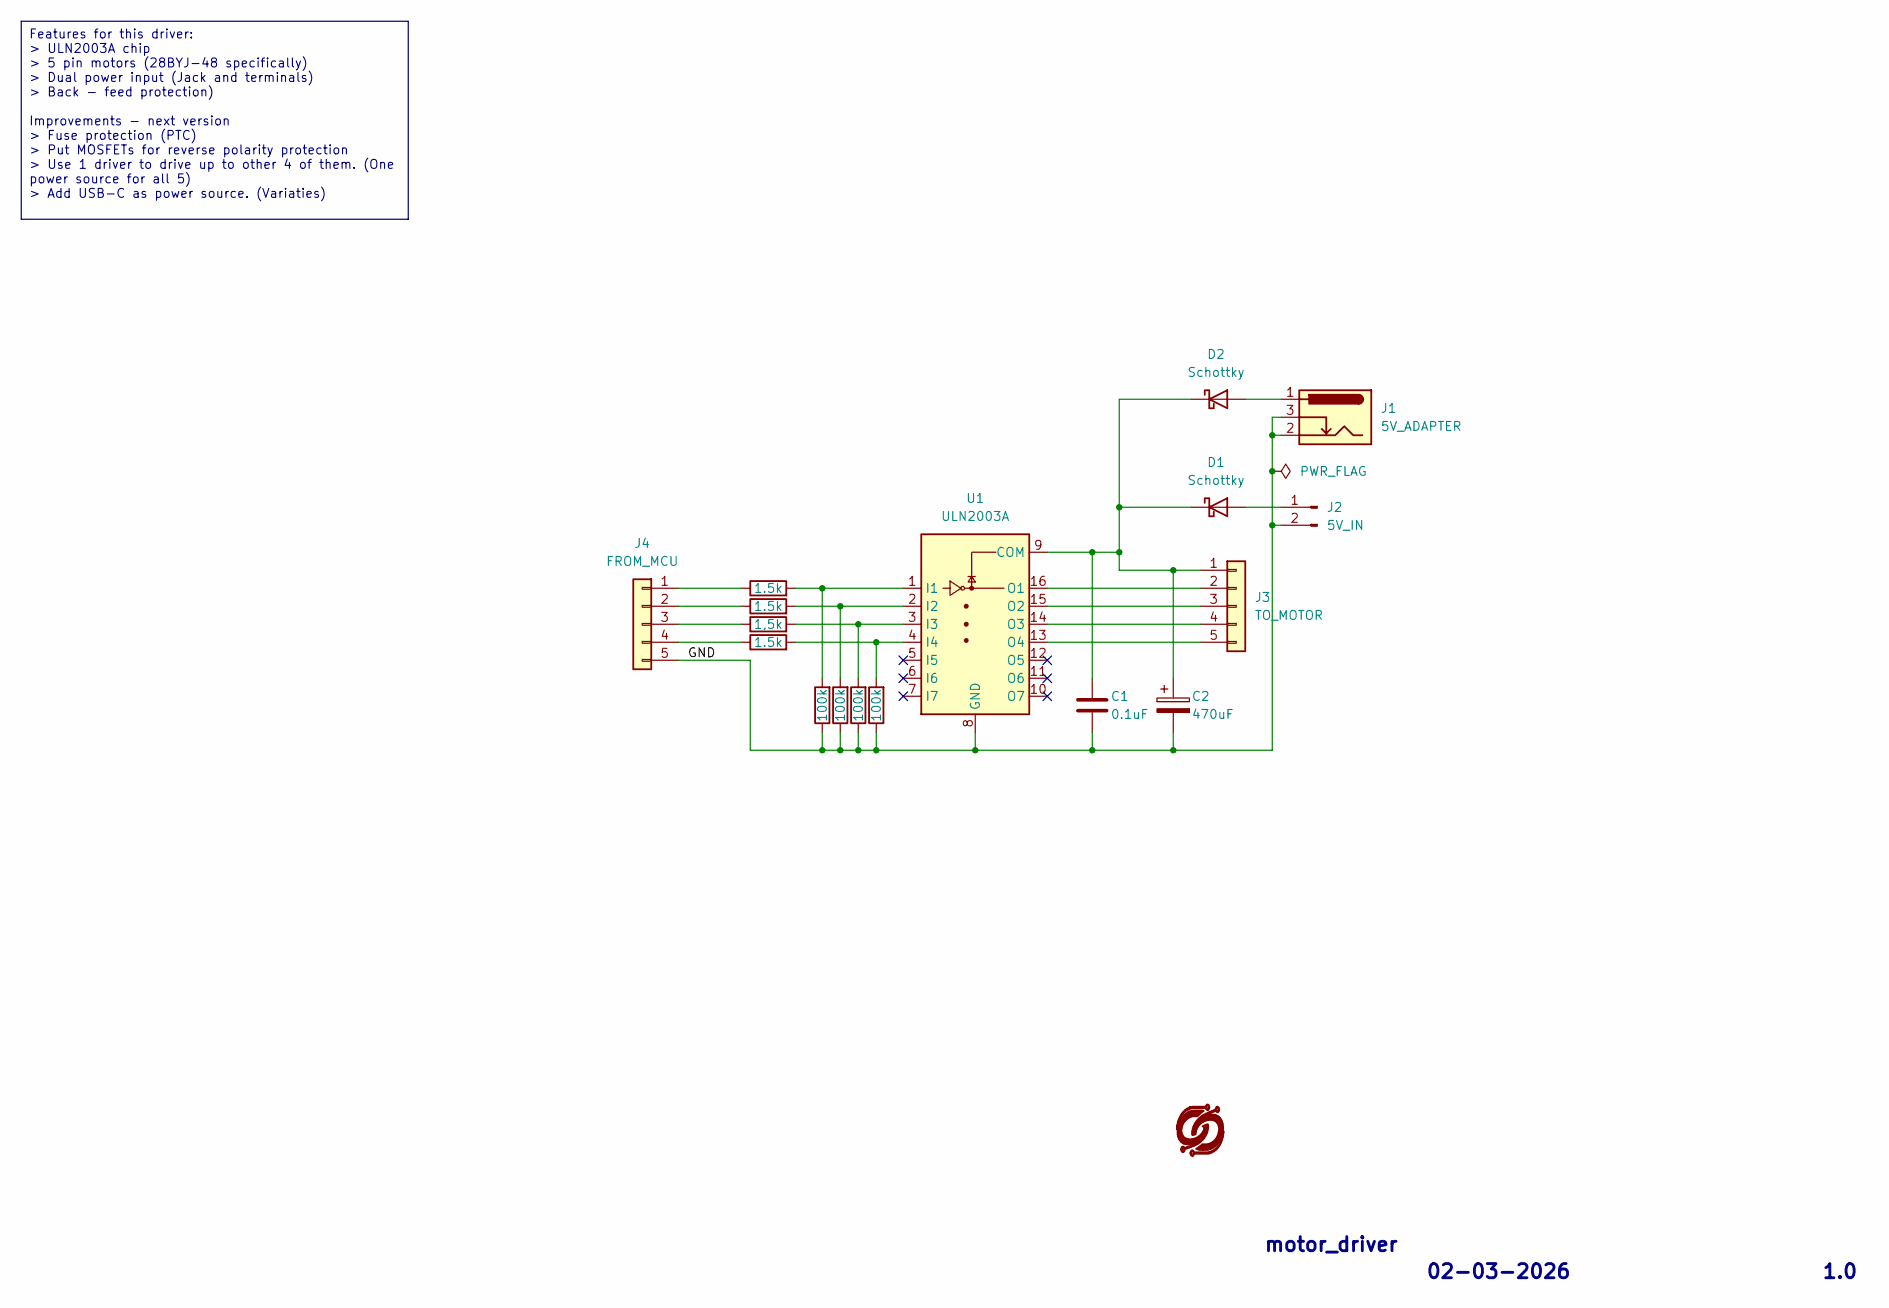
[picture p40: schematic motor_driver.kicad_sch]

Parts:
C1: 0.1uF; C_0805_2012Metric_Pad1.18x1.45mm_HandSolder
C2: 470uF; CP_Radial_D10.0mm_P5.00mm
D1, D2: Schottky; D_DO-201AD_P15.24mm_Horizontal
J1: 5V_ADAPTER; BarrelJack_GCT_DCJ200-10-A_Horizontal
J2: 5V_IN; PinHeader_1x02_P2.54mm_Vertical
J3: TO_MOTOR; JST_XH_B5B-XH-A_1x05_P2.50mm_Vertical
J4: FROM_MCU; PinHeader_1x05_P2.54mm_Vertical
R1, R2, R4: 1.5k; R_0805_2012Metric_Pad1.20x1.40mm_HandSolder
R3: 1,5k; R_0805_2012Metric_Pad1.20x1.40mm_HandSolder
R5, R6, R7, R8: 100k; R_0805_2012Metric_Pad1.20x1.40mm_HandSolder
U1: ULN2003A; DIP-16_W7.62mm_Socket

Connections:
/GND: C1.2, C2.2, J1.2, J1.3, J2.2, J4.5, R5.1, R6.1, R7.1, R8.1, U1.8 (GND)
unnamed: D1.2 (A), J2.1
unnamed: C1.1, C2.1, D1.1 (K), D2.1 (K), J3.1, U1.9 (COM)
unnamed: D2.2 (A), J1.1
unnamed: J3.2, U1.16 (O1)
unnamed: J3.3, U1.15 (O2)
unnamed: J3.4, U1.14 (O3)
unnamed: J3.5, U1.13 (O4)
unnamed: J4.1, R1.1
unnamed: J4.2, R2.1
unnamed: J4.3, R3.1
unnamed: J4.4, R4.1
unnamed: R1.2, R8.2, U1.1 (I1)
unnamed: R2.2, R7.2, U1.2 (I2)
unnamed: R3.2, R6.2, U1.3 (I3)
unnamed: R4.2, R5.2, U1.4 (I4)

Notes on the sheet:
Features for this driver: > ULN2003A chip > 5 pin motors (28BYJ-48 specifically) > Dual power input (Jack and terminals) > Back - feed protection) Improvements - next version > Fuse protection (PTC) > Put MOSFETs for reverse polarity protection > Use 1 driver to drive up to other 4 of them. (One po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
motor_driver
02-03-2026
1.0

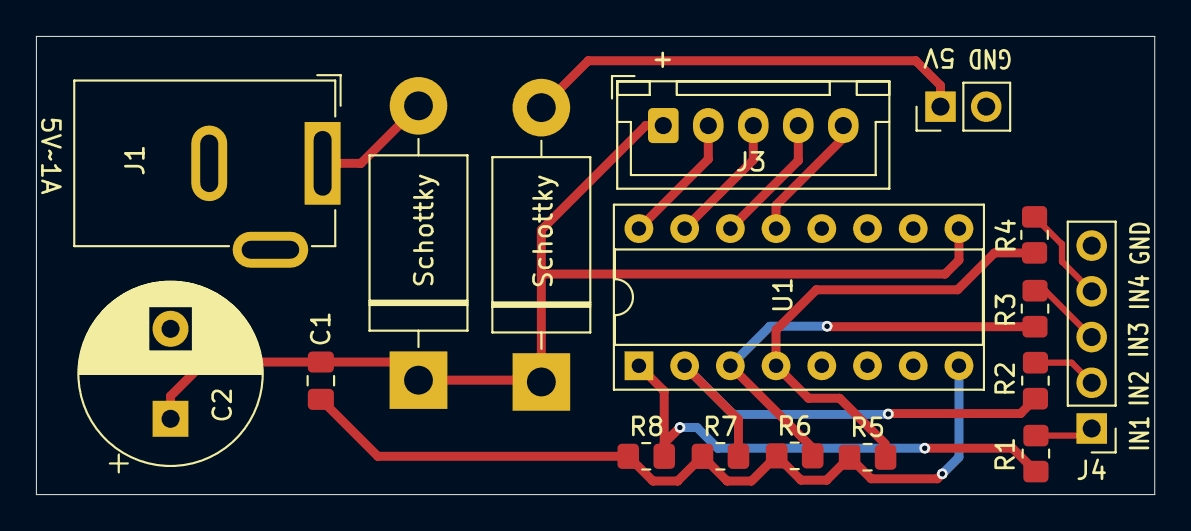
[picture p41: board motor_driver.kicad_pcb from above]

Board: 2 copper layers, 62.1 x 25.5 mm, 17 parts (0 on the bottom side), 16 nets.

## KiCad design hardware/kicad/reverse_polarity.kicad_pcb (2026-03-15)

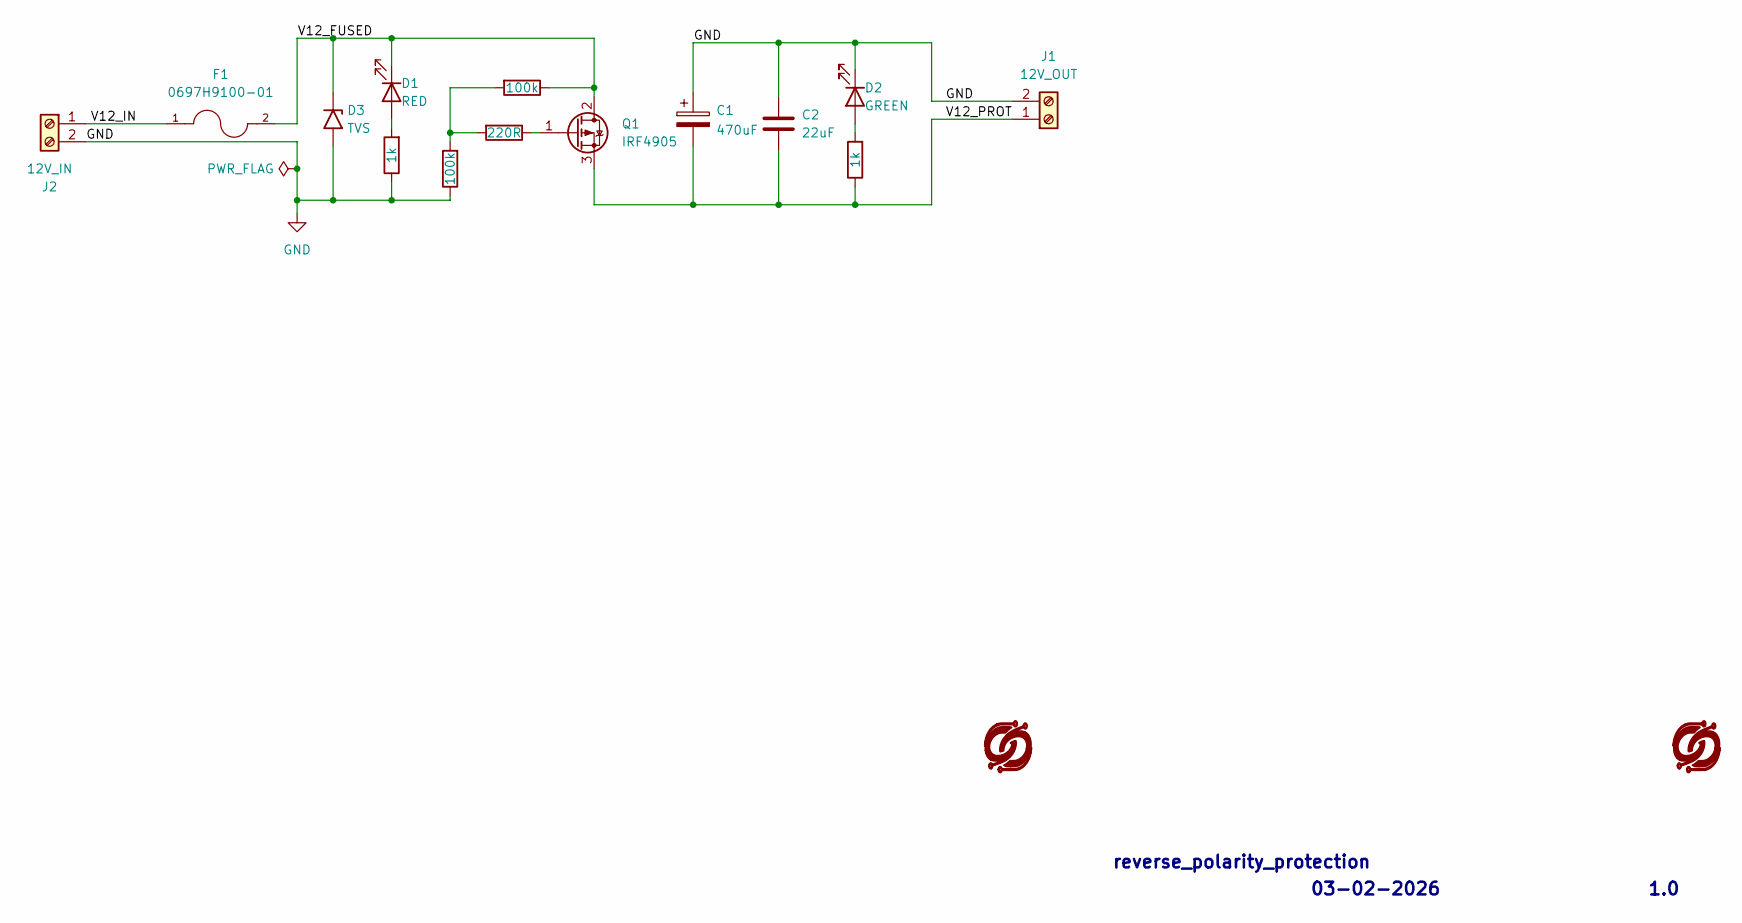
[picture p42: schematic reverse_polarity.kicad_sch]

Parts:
C1: 470uF; CP_Radial_D10.0mm_P5.00mm
C2: 22uF; C_0805_2012Metric_Pad1.18x1.45mm_HandSolder
D1: RED; LED_D3.0mm
D2: GREEN; LED_D3.0mm
D3: TVS; D_DO-201AE_P15.24mm_Horizontal
F1: 0697H9100-01; FUSRR508W60L835T400H810; PARTREV Jan2019
J1: 12V_OUT; CUI_TB002-500-02BE
J2: 12V_IN; CUI_TB002-500-02BE
Q1: IRF4905; TO-220-3_Vertical
R1, R5: 100k; R_0805_2012Metric_Pad1.20x1.40mm_HandSolder
R2: 220R; R_0805_2012Metric_Pad1.20x1.40mm_HandSolder
R3, R4: 1k; R_Axial_DIN0207_L6.3mm_D2.5mm_P10.16mm_Horizontal

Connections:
/V12_FUSED: D1.1 (K), D3.1 (A1), F1.2, Q1.2 (D), R1.1
/V12_IN: F1.1, J2.1
/V12_PROT: C1.2, C2.2, J1.1, Q1.3 (S), R4.1
GND: C1.1, C2.1, D2.1 (K), D3.2 (A2), J1.2, J2.2, R3.1, R5.1
unnamed: D1.2 (A), R3.2
unnamed: D2.2 (A), R4.2
unnamed: Q1.1 (G), R2.1
unnamed: R1.2, R2.2, R5.2

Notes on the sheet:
reverse_polarity_protection
03-02-2026
1.0

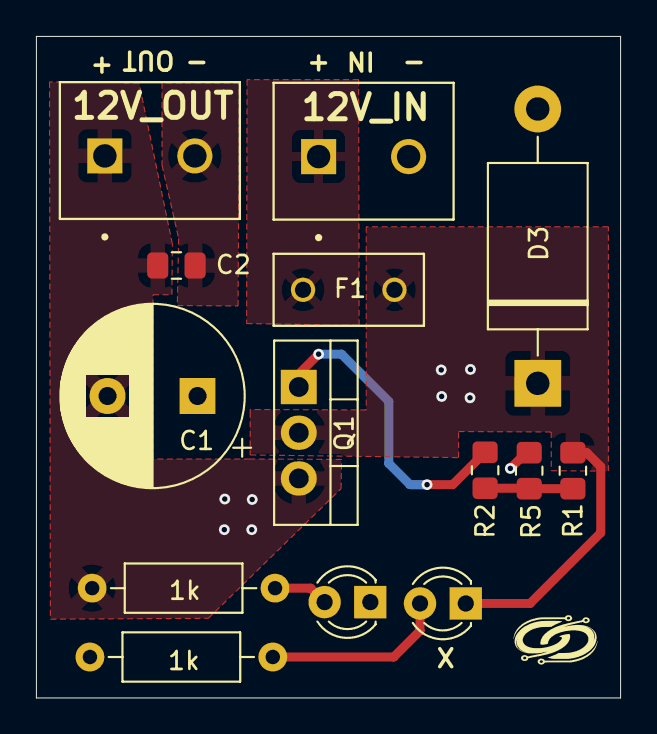
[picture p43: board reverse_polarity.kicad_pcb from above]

Board: 2 copper layers, 32.5 x 36.7 mm, 14 parts (0 on the bottom side), 8 nets.

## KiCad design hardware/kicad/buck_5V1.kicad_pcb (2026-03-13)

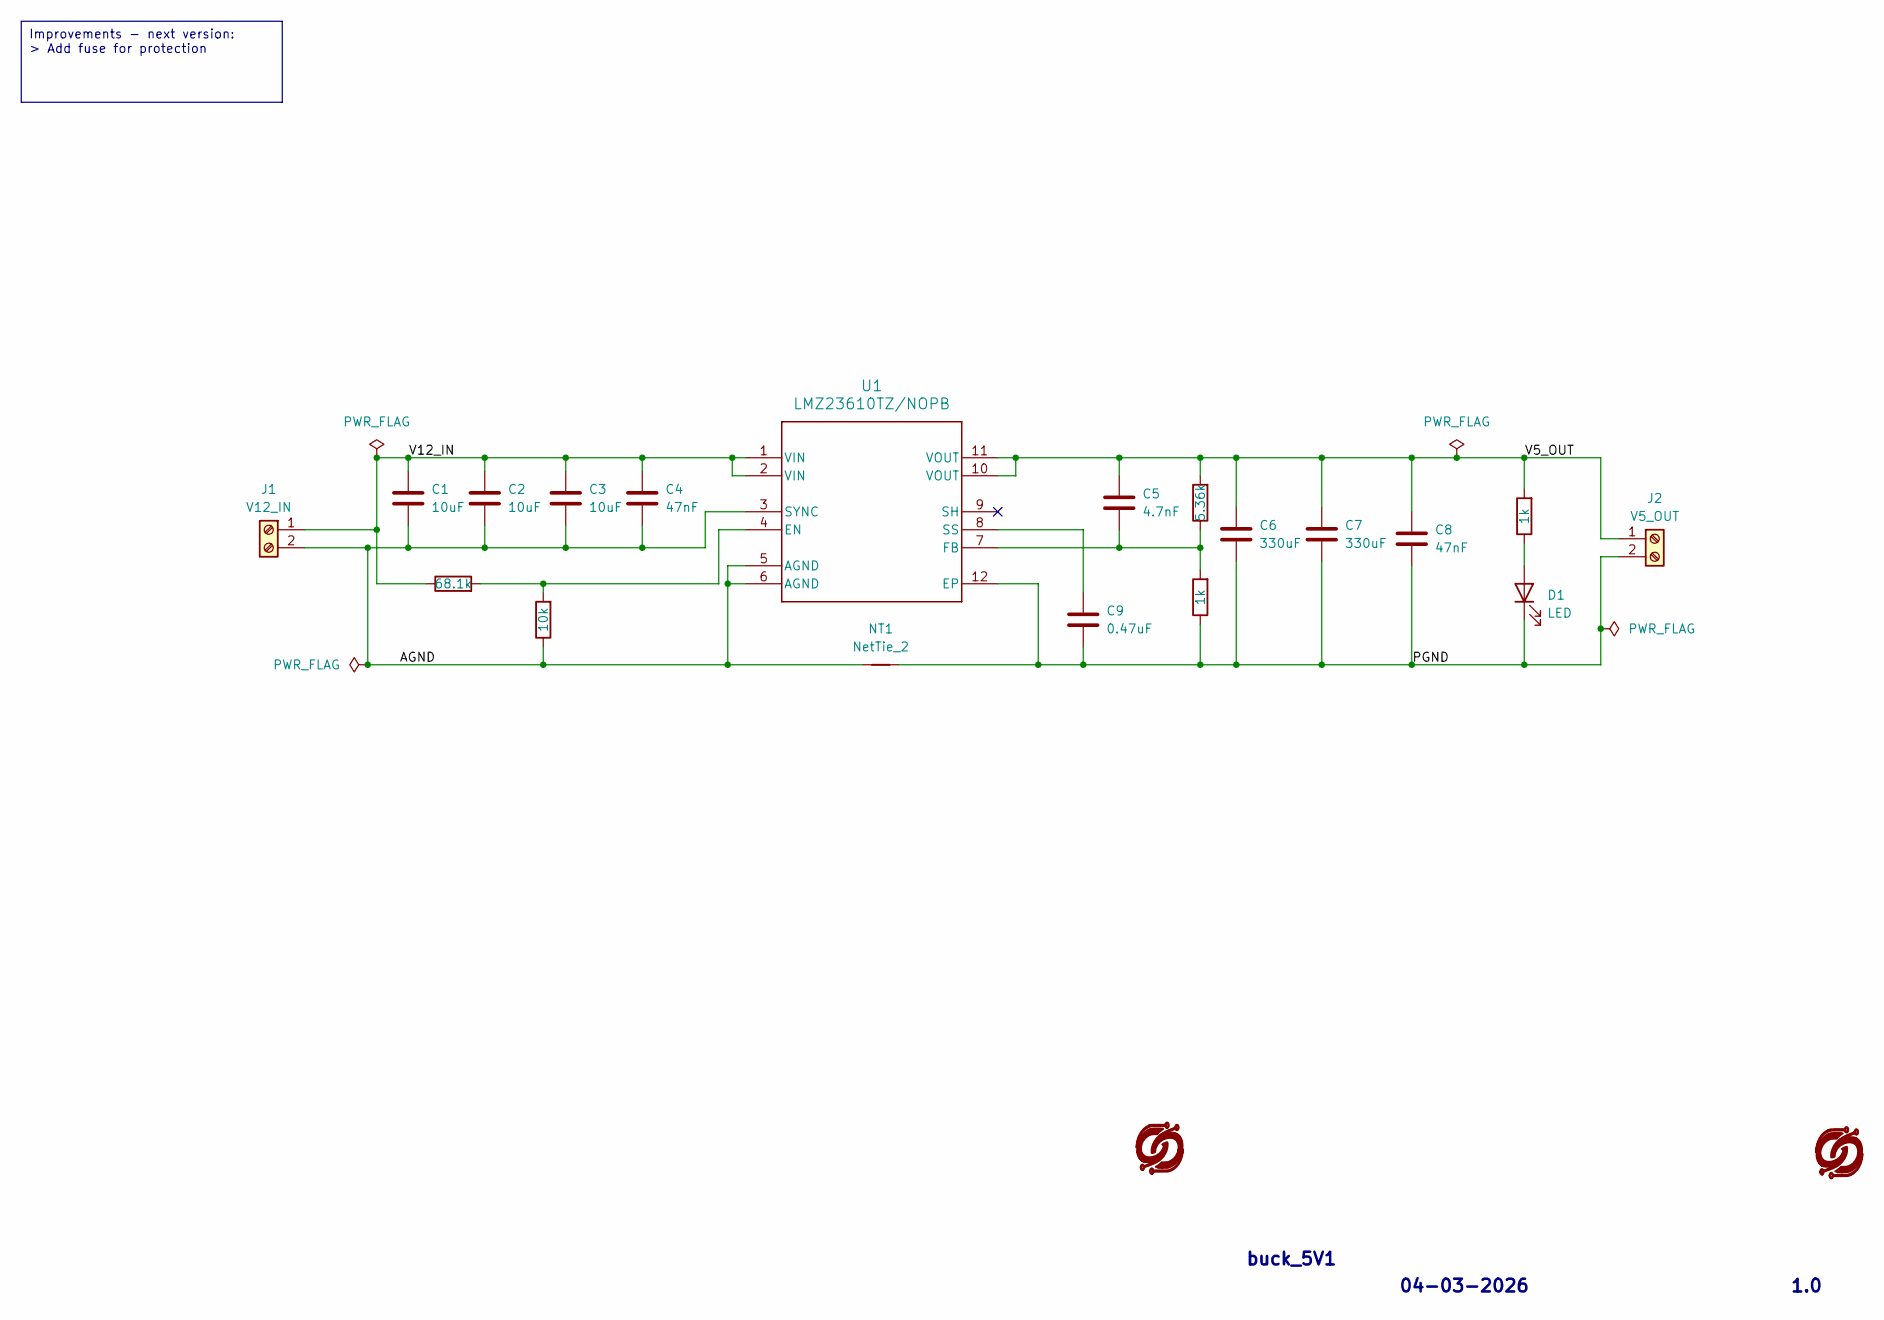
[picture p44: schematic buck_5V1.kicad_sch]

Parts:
C1, C2, C3: 10uF; C_0805_2012Metric_Pad1.18x1.45mm_HandSolder
C4, C8: 47nF; C_0805_2012Metric_Pad1.18x1.45mm_HandSolder
C5: 4.7nF; C_0805_2012Metric_Pad1.18x1.45mm_HandSolder
C6, C7: 330uF; C_Radial_D6.3mm_H5.0mm_P2.50mm
C9: 0.47uF; C_0805_2012Metric_Pad1.18x1.45mm_HandSolder
D1: LED; LED_D3.0mm
J1: V12_IN; CUI_TB002-500-02BE
J2: V5_OUT; CUI_TB002-500-02BE
NT1: NetTie_2; NetTie-2_SMD_Pad2.0mm
R1: 5.36k; R_0805_2012Metric_Pad1.20x1.40mm_HandSolder
R2, R4: 1k; R_0805_2012Metric_Pad1.20x1.40mm_HandSolder
R3: 68.1k; R_0805_2012Metric_Pad1.20x1.40mm_HandSolder
R5: 10k; R_0805_2012Metric_Pad1.20x1.40mm_HandSolder
U1: LMZ23610TZ/NOPB; NDY0011A_L

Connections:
/AGND: C1.2, C2.2, C3.2, C4.2, J1.2, NT1.1, R5.1, U1.3 (SYNC), U1.5 (AGND), U1.6 (AGND)
/PGND: C6.2, C7.2, C8.2, C9.2, D1.1 (K), J2.2, NT1.2, R4.1, U1.12 (EP)
/V5_OUT: C5.1, C6.1, C7.1, C8.1, J2.1, R1.2, R2.2, U1.10 (VOUT), U1.11 (VOUT)
/V12_IN: C1.1, C2.1, C3.1, C4.1, J1.1, R3.1, U1.1 (VIN), U1.2 (VIN)
unnamed: D1.2 (A), R2.1
unnamed: R3.2, R5.2, U1.4 (EN)
unnamed: C5.2, R1.1, R4.2, U1.7 (FB)
unnamed: C9.1, U1.8 (SS)

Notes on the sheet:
Improvements - next version: > Add fuse for protection
1.0
04-03-2026
buck_5V1

Board: 2 copper layers, 19 parts (0 on the bottom side), 8 nets, no tracks yet.

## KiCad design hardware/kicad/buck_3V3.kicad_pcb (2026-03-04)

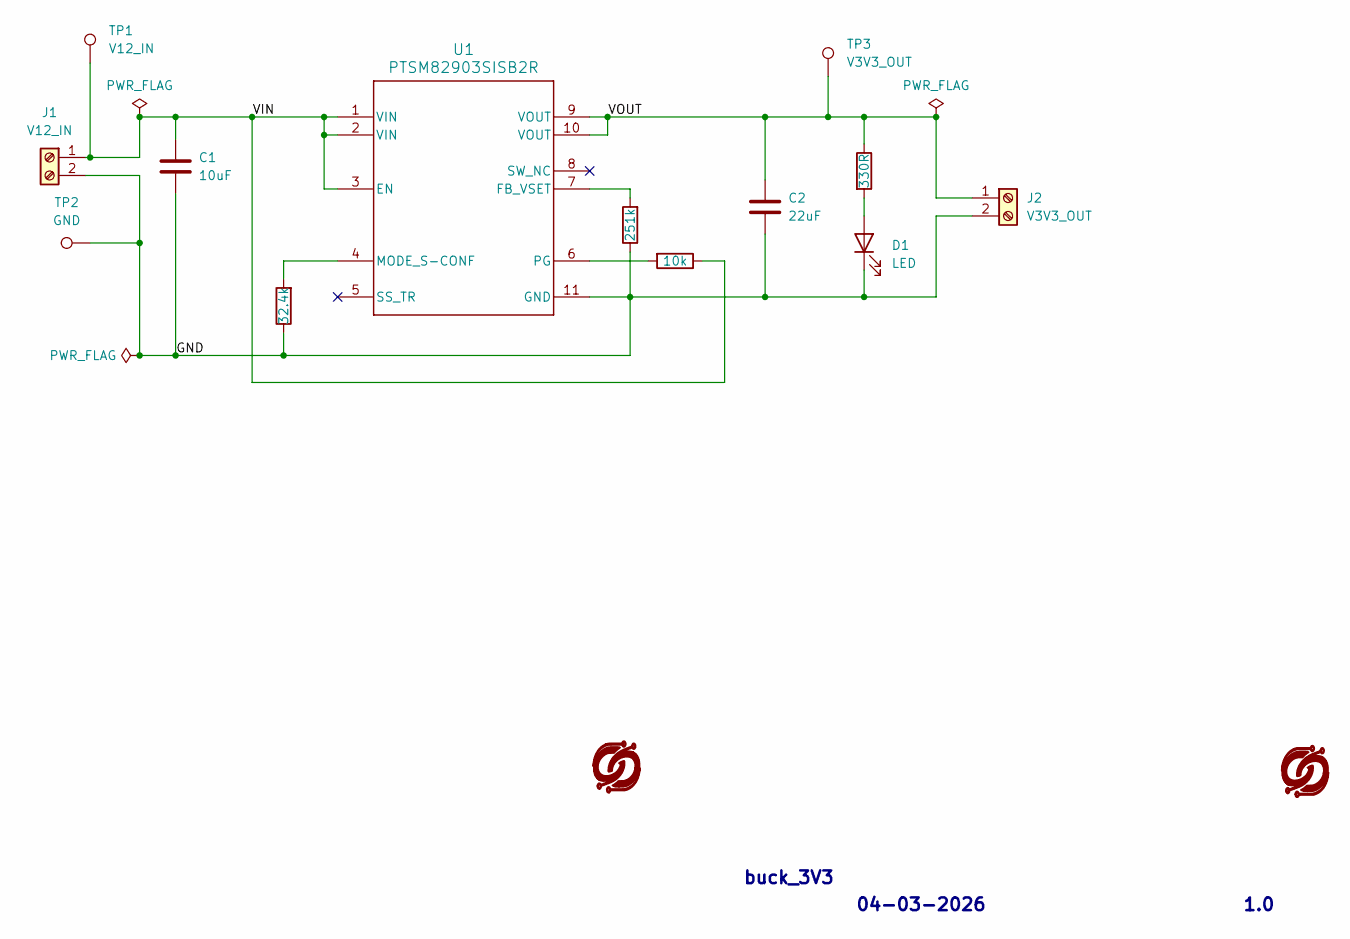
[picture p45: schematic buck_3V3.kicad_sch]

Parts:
C1: 10uF; C_Rect_L7.0mm_W3.5mm_P5.00mm
C2: 22uF; C_Rect_L7.0mm_W3.5mm_P5.00mm
D1: LED; LED_D3.0mm
J1: V12_IN; CUI_TB002-500-02BE
J2: V3V3_OUT; CUI_TB002-500-02BE
R1: 32.4k; R_Axial_DIN0207_L6.3mm_D2.5mm_P10.16mm_Horizontal
R2: 251k; R_Axial_DIN0207_L6.3mm_D2.5mm_P10.16mm_Horizontal
R3: 10k; R_Axial_DIN0207_L6.3mm_D2.5mm_P10.16mm_Horizontal
R4: 330R; R_Axial_DIN0207_L6.3mm_D2.5mm_P10.16mm_Horizontal
TP1: V12_IN; TestPoint_Pad_D2.5mm
TP2: GND; TestPoint_Pad_D2.5mm
TP3: V3V3_OUT; TestPoint_Pad_D2.5mm
U1: PTSM82903SISB2R; SIS0011A-MFG

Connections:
/GND: C1.2, C2.2, D1.1 (K), J1.2, J2.2, R1.1, R2.1, TP2.1, U1.11 (GND)
/VIN: C1.1, J1.1, R3.1, TP1.1, U1.1 (VIN), U1.2 (VIN), U1.3 (EN)
/VOUT: C2.1, J2.1, R4.1, TP3.1, U1.9 (VOUT), U1.10 (VOUT)
unnamed: D1.2 (A), R4.2
unnamed: R2.2, U1.7 (FB_VSET)
unnamed: R1.2, U1.4 (MODE_S-CONF)
unnamed: R3.2, U1.6 (PG)

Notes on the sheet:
1.0
buck_3V3
04-03-2026

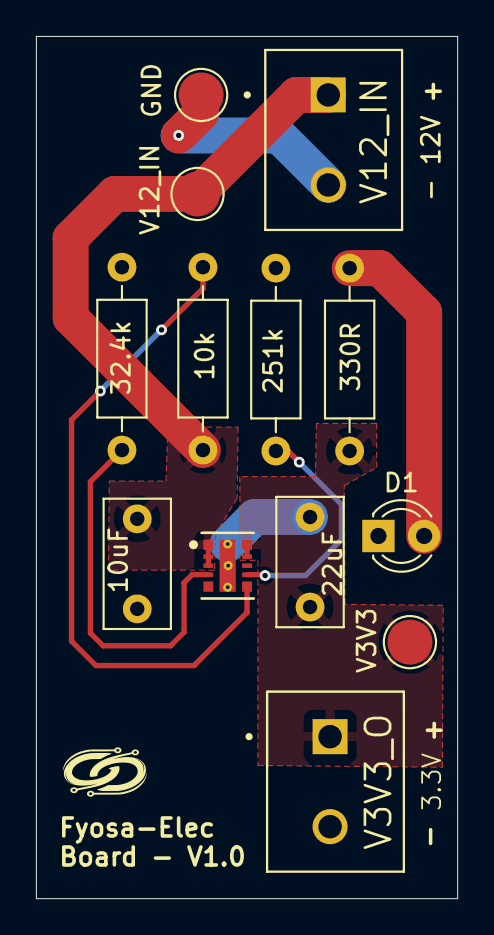
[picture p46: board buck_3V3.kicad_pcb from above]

Board: 2 copper layers, 23.4 x 47.9 mm, 13 parts (0 on the bottom side), 7 nets.

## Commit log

2026-01-20 Added raspberry pi folder
2026-02-09 doc: stm32-nucleo user manual added
2026-02-10 feat: calibrator physical with GUI
2026-02-12 feat: started power schematic - power connector 12V
2026-02-13 feat: added 12V input protection - reverse polarity
2026-02-13 feat: bulk capacitors added - both rails
2026-02-13 docs: additional notes - power choices
2026-02-16 feat: added buck converter 12-5V logic rail - and its docs
2026-02-16 fix: refined buck converter - 12V to 5V
2026-02-18 docs: shifted from easyeda to kicad
2026-02-18 feat: power blocks design - kicad restart
    [BUCK_3V3.kicad_sch, BUCK_5V.kicad_sch, MCU_INTERFACES.kicad_sch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]
2026-02-19 feat: added buck 12-5 & 12-3V3 layouts
    [BUCK_3V3.kicad_sch, BUCK_5V.kicad_sch]
2026-02-19 feat: buck 12-3.3V schematic structure complete
    [BUCK_3V3.kicad_sch, POWER.kicad_sch]
2026-02-20 fix: changed to TPSM82903 - PG not connected yet
    [BUCK_3V3.kicad_sch, POWER.kicad_sch]
2026-02-20 feat: mcu interfaces & motor connections
    [BUCK_5V.kicad_sch, MCU_INTERFACES.kicad_sch, MOTORS.kicad_sch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]
2026-02-20 feat: implemented keypad & reverse polarity protection
    [KEYPAD_4X4.kicad_sch, POWER.kicad_sch, REV_POL_PROT.kicad_sch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]
2026-02-21 fix: error fixing & connection config
    [BUCK_3V3.kicad_sch, BUCK_5V.kicad_sch, KEYPAD_4X4.kicad_sch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]
2026-02-22 docs: added end semester report for project
    [BUCK_3V3.kicad_sch, BUCK_5V.kicad_sch, KEYPAD_4X4.kicad_sch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]
2026-02-23 doc: refined end-semester-one report
    [POWER.kicad_sch]
2026-02-23 chore: deleted schematic files
    [BUCK_3V3.kicad_sch, BUCK_5V.kicad_sch, KEYPAD_4X4.kicad_sch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]
2026-02-23 feat: added reverse polarity circuit
    [card_issuance.kicad_pcb, card_issuance.kicad_sch, power.kicad_sch]
2026-02-23 feat: added buck converter 12V to 3V3
    [buck_3v3.kicad_sch, buck_5.1.kicad_sch, power.kicad_sch]
2026-02-23 feat: added buck converter 12V to 5V
    [buck_3v3.kicad_sch, buck_5.1.kicad_sch, power.kicad_sch]
2026-02-24 fix: footprint issues and library conflicts - KiCAD
    [buck_3v3.kicad_sch, buck_5.1.kicad_sch, power.kicad_sch]
2026-02-24 fix: protection circuit - MOSFET & enable config
    [buck_5.1.kicad_sch, card_issuance.kicad_sch, power.kicad_sch]
2026-02-24 feat: separated modules but added power module
    [buck_3v3.kicad_sch, buck_5.1.kicad_sch, card_issuance.kicad_sch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]
2026-02-25 fix: buck connections
    [buck_3v3.kicad_sch, buck_5.1.kicad_sch, card_issuance_power.kicad_pcb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]
2026-02-27 docs: datasheet for buck converter added
2026-02-27 feat: added settings - pcb design
    [card_issuance_power.kicad_pcb, card_issuance_power.kicad_sch]
2026-02-27 chore: pcb board components placements
    [card_issuance_power.kicad_pcb]
2026-02-27 chore: pcb planes filling & vias
    [card_issuance_power.kicad_pcb, card_issuance_power.kicad_sch]
2026-02-28 feat: added motor driver circuit
    [card_issuance_power.kicad_pcb, motor_driver.kicad_pcb, motor_driver.kicad_sch]
2026-03-01 feat: added reverse polarity protection
    [motor_driver.kicad_sch]
2026-03-01 feat: added motor-driver simulations
2026-03-01 perf: changed mosfet to diodes - polarity protection
    [motor_driver.kicad_sch]
2026-03-01 feat: schematic to simulation circuit - not yet simulated
    [motor_driver.kicad_sch]
2026-03-02 feat: added pcb board and components placements
    [motor_driver.kicad_pcb, motor_driver.kicad_sch]
2026-03-02 perf: routed the components - PCB
    [motor_driver.kicad_pcb, motor_driver.kicad_sch]
2026-03-02 docs: added exports schematic & pcb
    [buck_3v3.kicad_sch, buck_5.1.kicad_sch, card_issuance.kicad_pcb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]
2026-03-02 docs: bom generated and updated schematics
    [motor_driver.csv, motor_driver.kicad_pcb, motor_driver.kicad_sch]
2026-03-03 feat: implemented simulation for reverse polarity protection
    [motor_driver.kicad_pcb, reverse_polarity.kicad_pcb, reverse_polarity.kicad_sch]
2026-03-03 feat: implemented schematics of protection
    [reverse_polarity.kicad_sch]
2026-03-03 perf: refined protection circuit
    [reverse_polarity.kicad_sch]
2026-03-03 feat: added buck_5V1 schematic
    [buck_5V1.kicad_pcb, buck_5V1.kicad_sch]
2026-03-03 docs: added export schem for protection circuit
    [buck_5V1.kicad_sch]
2026-03-03 feat: added buck_3V3 schematic
    [buck_3V3.kicad_pcb, buck_3V3.kicad_sch]
2026-03-03 docs: schematic export of buck converters - 12V to 5V1 & 3V3
2026-03-04 docs: edited end-semester-report
    [buck_3V3.kicad_sch]
2026-03-04 feat: added pcb to buck3V3
    [buck_3V3.kicad_pcb, buck_3V3.kicad_sch]
2026-03-04 feat: added pcb for buck 5V1
    [buck_3V3.kicad_sch, buck_5V1.kicad_pcb, buck_5V1.kicad_sch]
2026-03-05 docs: added pcb export - buck_5V1
    [buck_5V1.kicad_pcb]
2026-03-05 docs: added pcb export - buck_3V3
    [motor_driver.kicad_pcb]
2026-03-05 feat: added reverse polarity protection pcb
    [reverse_polarity.kicad_pcb, reverse_polarity.kicad_sch]
2026-03-06 docs: 3d files for design added
    [reverse_polarity.kicad_pcb]
2026-03-13 fix: smd packages for reverse polarity & board orientation
    [motor_driver.kicad_pcb, reverse_polarity.kicad_pcb, reverse_polarity.kicad_sch]
2026-03-13 fix: package change & pcb comp placement - buck5V1
    [buck_5V1.kicad_pcb, buck_5V1.kicad_sch]
2026-03-15 docs: added bom, 3d & prints(pcb) - reverse polarity
    [reverse_polarity.csv, reverse_polarity.kicad_pcb, reverse_polarity.kicad_sch]
2026-03-15 fix: 3d, pcb & packages - motor driver
    [motor_driver.csv, motor_driver.kicad_pcb, motor_driver.kicad_sch]
